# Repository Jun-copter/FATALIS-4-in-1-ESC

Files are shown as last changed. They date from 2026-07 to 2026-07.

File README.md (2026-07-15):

# FATALIS — 4-in-1 ESC

> **⚠ Work in Progress** — PCB layout and schematic are still under active development. Not yet sent for fabrication.

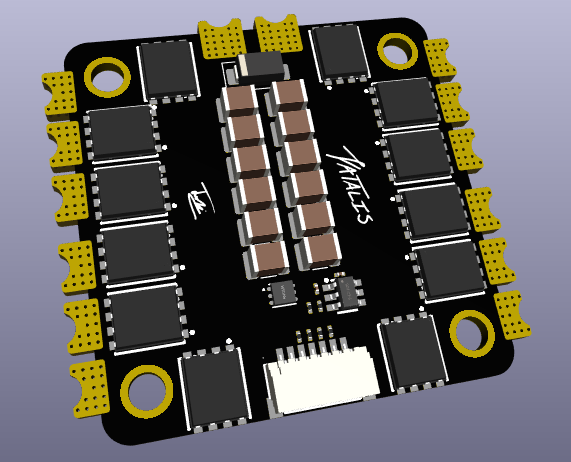
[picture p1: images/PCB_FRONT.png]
PCB 3D render (front)


<em>3D render — in progress, not final</em>

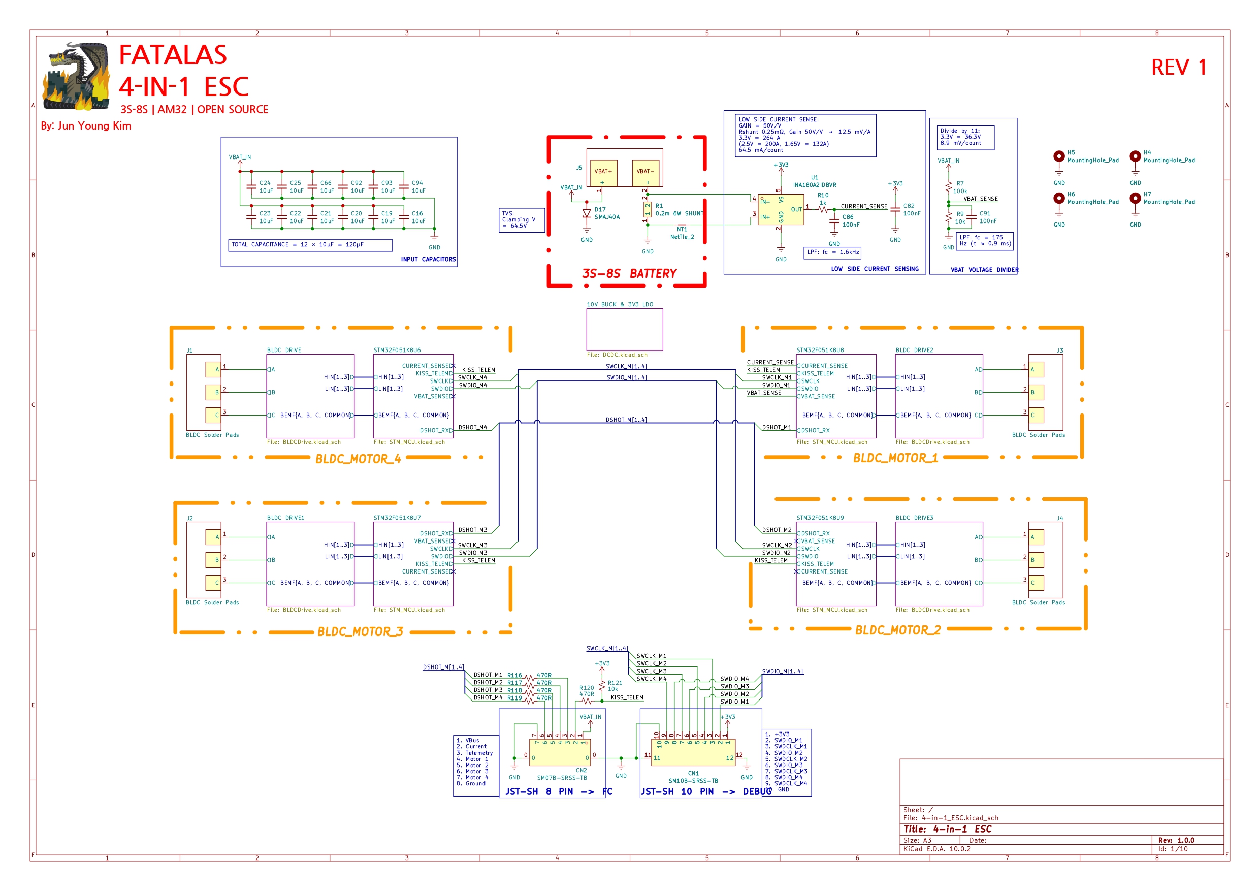
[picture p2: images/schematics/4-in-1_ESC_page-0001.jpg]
Top-level schematic


<em>Top-level schematic</em>

A compact 4-in-1 brushless ESC designed for high-performance FPV racing and freestyle drones. Four independent motor drives on a single 40×40mm 6-layer PCB, each rated 45A continuous / 90A burst per motor, running AM32 open-source firmware on an STM32G071. Sponsored by PCBWay.

---

## Specifications

| Parameter | Value |
|---|---|
| Input voltage | 3–8S LiPo (11–33.6V) |
| Continuous current | 45A per motor (phase current, with prop-wash airflow) |
| Burst current | 90A per motor (phase current, <10s) |
| Max input current | ~160A total board (4 motors at full throttle) |
| PCB size | 40mm × 40mm |
| PCB layers | 6 |
| MCU | STM32G071GBU6 × 4 (one per motor) |
| Firmware | AM32 (open-source) |
| MOSFETs | Infineon BSC070N10NS3G (100V, 7mΩ) |
| Gate driver | JSM6288Q half-bridge |
| Power regulator | TI LMR51610 buck (→10V) + TI TLV76733 LDO (→3.3V) |
| Protocols | DShot150/300/600, Oneshot125/42, Multishot, PWM |
| Telemetry | KISS / AM32 ESC telemetry (RPM, current, voltage, temperature) |
| Sensing | Per-motor current, battery voltage, temperature |

---

## Board Design

### Power Architecture

The input rail accepts 3–8S LiPo (up to 33.6V) and feeds directly into the MOSFET phase bridges. A TI **LMR51610** wide-VIN synchronous buck converter steps the battery voltage down to 10V at 400kHz, sized with a 56µH inductor and 22µF output filter for low ripple. A TI **TLV76733** LDO then regulates the 10V rail to a clean 3.3V supply for the MCUs and logic. Input bulk capacitors are 100V-rated ceramics with capacitance derating analysis applied (~50% effective capacitance at DC bias), ensuring adequate hold-up under the fast transients of motor switching.

### MOSFET Phase Bridges

Each of the four motor drives uses six **Infineon BSC070N10NS3G** N-channel MOSFETs (100V, 7mΩ) arranged in a standard 3-phase half-bridge topology. The 100V rating provides margin above the maximum 33.6V battery voltage, accounting for inductive flyback spikes during hard switching. Gate resistors and RC snubbers suppress ringing on the switch node without significantly degrading switching speed. The continuous current rating is thermally derived: at 45A phase current, conduction losses across the two active MOSFETs (I²×2×R_DS(on)_hot) stay within the thermal budget of the 6-layer copper pours under prop-wash cooling, keeping junction temperature below 125°C with a 50°C ambient.

### Gate Drive

**JSM6288Q** bootstrap half-bridge gate drivers provide high-current drive capability for fast MOSFET switching, with integrated bootstrap diodes charging the high-side gate supply on each PWM cycle. Bootstrap capacitors are sized to maintain sufficient gate drive voltage across the full duty-cycle range at maximum switching frequency.

### MCU & Firmware

Each motor channel has a dedicated **STM32G071GBU6** (Cortex-M0+, 64MHz) running **AM32** open-source ESC firmware. AM32's timer-based protocol auto-detection supports DShot150/300/600, Oneshot125/42, Multishot, and standard PWM without manual configuration. The STM32G071's advanced timers handle 3-phase complementary PWM generation with configurable dead-time insertion.

### Sensing & Telemetry

**Input current sensing** uses two **ASR-M-3-0.5F** (0.5mΩ, 6W, 2512) shunt resistors in parallel on the low side, giving an effective 0.25mΩ shunt rated 12W total. At maximum board input current (180A across all four motors at full throttle), each shunt carries 90A and dissipates 4.05W — within the 6W per-unit rating with comfortable margin. An **INA180A2IDBVR** current sense amplifier (gain = 50V/V) reads the differential voltage across the shunt; at 180A the output is 2.25V, well within the 3.3V ADC rail. Low-side placement keeps the common-mode voltage near 0V, so the INA180A2's 26V common-mode limit is not a concern across the full 3–8S input range.

**Per-motor current sensing** uses a dedicated low-side shunt on each phase leg, read by the STM32G071's internal ADC for real-time per-motor current feedback to AM32 firmware.

Battery voltage is monitored through a resistor divider, and an NTC thermistor on each motor channel provides board temperature. All sensor data is transmitted back to the flight controller over bidirectional DShot as KISS/AM32 telemetry frames, providing real-time RPM, current, voltage, and temperature at full loop rates.

### Thermal Design

Power dissipation analysis was performed on both the switching MOSFETs and the LMR51610 buck converter using junction-to-ambient and ψ_JB thermal metrics. At 45A continuous, conduction losses per motor (P = I²×2×R_DS(on)_hot ≈ 60W split across 6 MOSFETs) are managed by direct solder of exposed pads to the PCB and inner-layer copper pours acting as a thermal spreader. The 6-layer stackup provides additional thermal mass compared to a 4-layer design.

---

## Connectors

### 8-Pin JST — Flight Controller

| Pin | Signal |
|-----|---|
| 1 | VBus |
| 2 | Current |
| 3 | Telemetry |
| 4 | Motor 1 |
| 5 | Motor 2 |
| 6 | Motor 3 |
| 7 | Motor 4 |
| 8 | Ground |

### 10-Pin JST — Debug / SWD

| Pin | Signal |
|-----|---|
| 1 | +3V3 |
| 2 | SWDIO M1 |
| 3 | SWDCLK M1 |
| 4 | SWDIO M2 |
| 5 | SWDCLK M2 |
| 6 | SWDIO M3 |
| 7 | SWDCLK M3 |
| 8 | SWDIO M4 |
| 9 | SWDCLK M4 |
| 10 | GND |

---

## Schematics

### Top-Level Overview
<table>
  <tr>
    <td>PCB 3D render (front)</td>
    <td>Top-level schematic</td>
  </tr>
</table>

### BLDC Drive — Motor 1
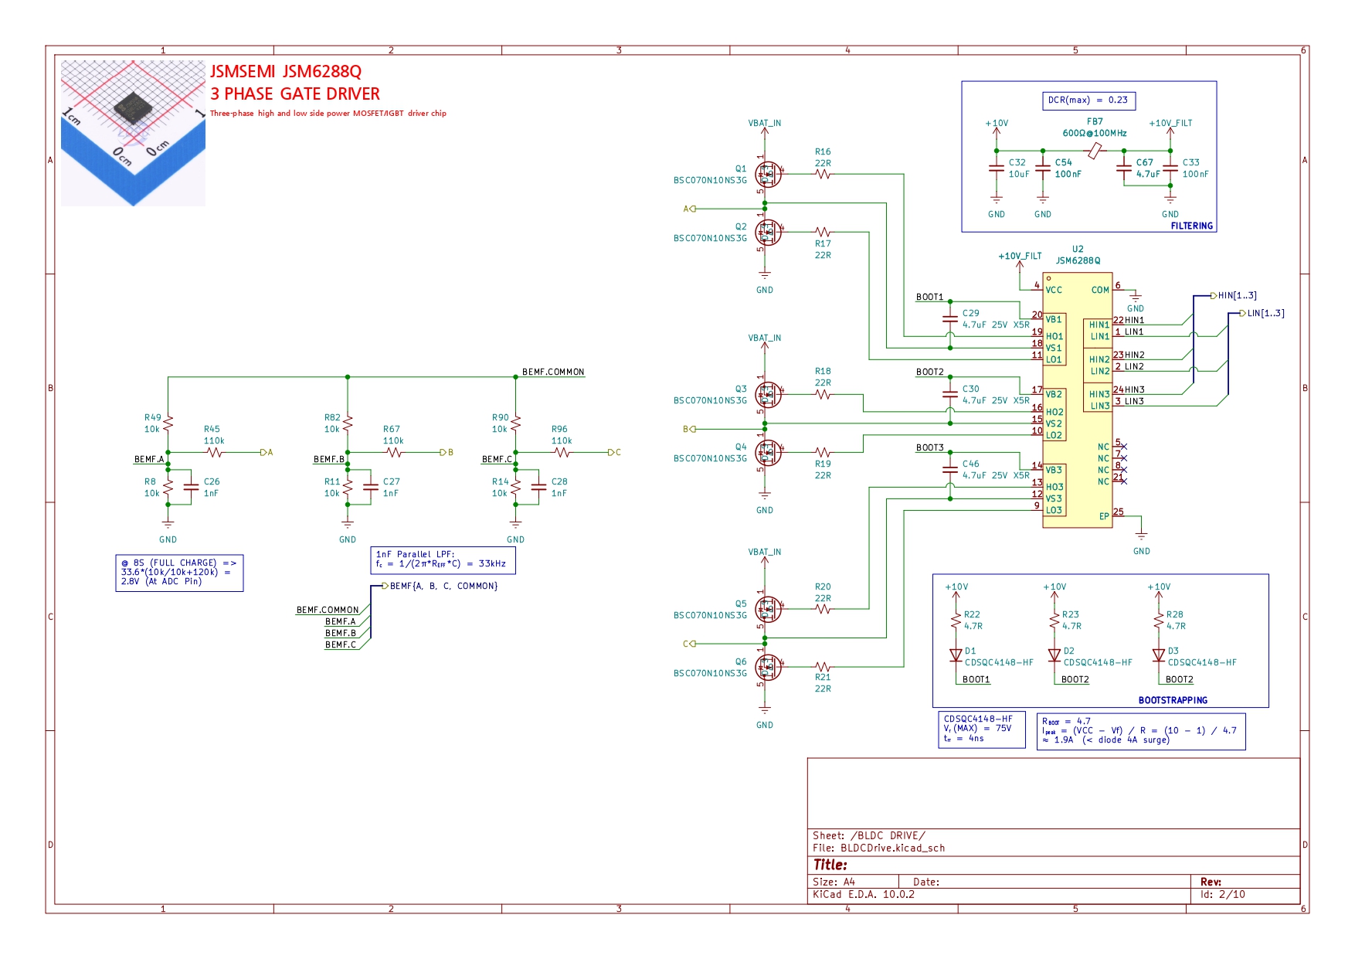
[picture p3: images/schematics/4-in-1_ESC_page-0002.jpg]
BLDC Drive Motor 1


### MCU — Motor 1 (STM32G071GBU6)
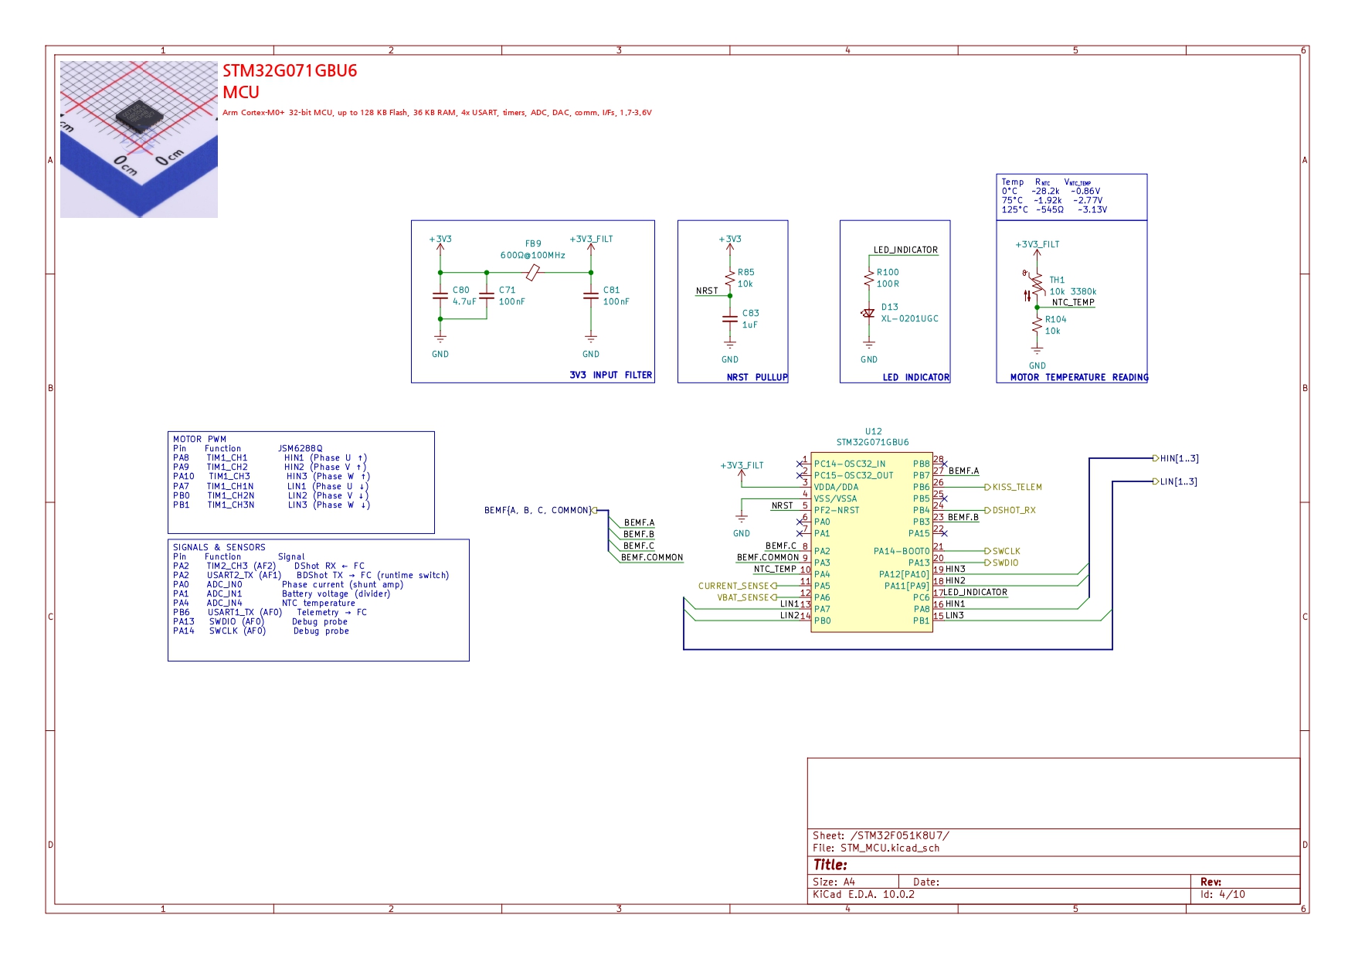
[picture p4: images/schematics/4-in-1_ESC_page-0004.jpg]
MCU Motor 1


### BLDC Drive — Motor 2
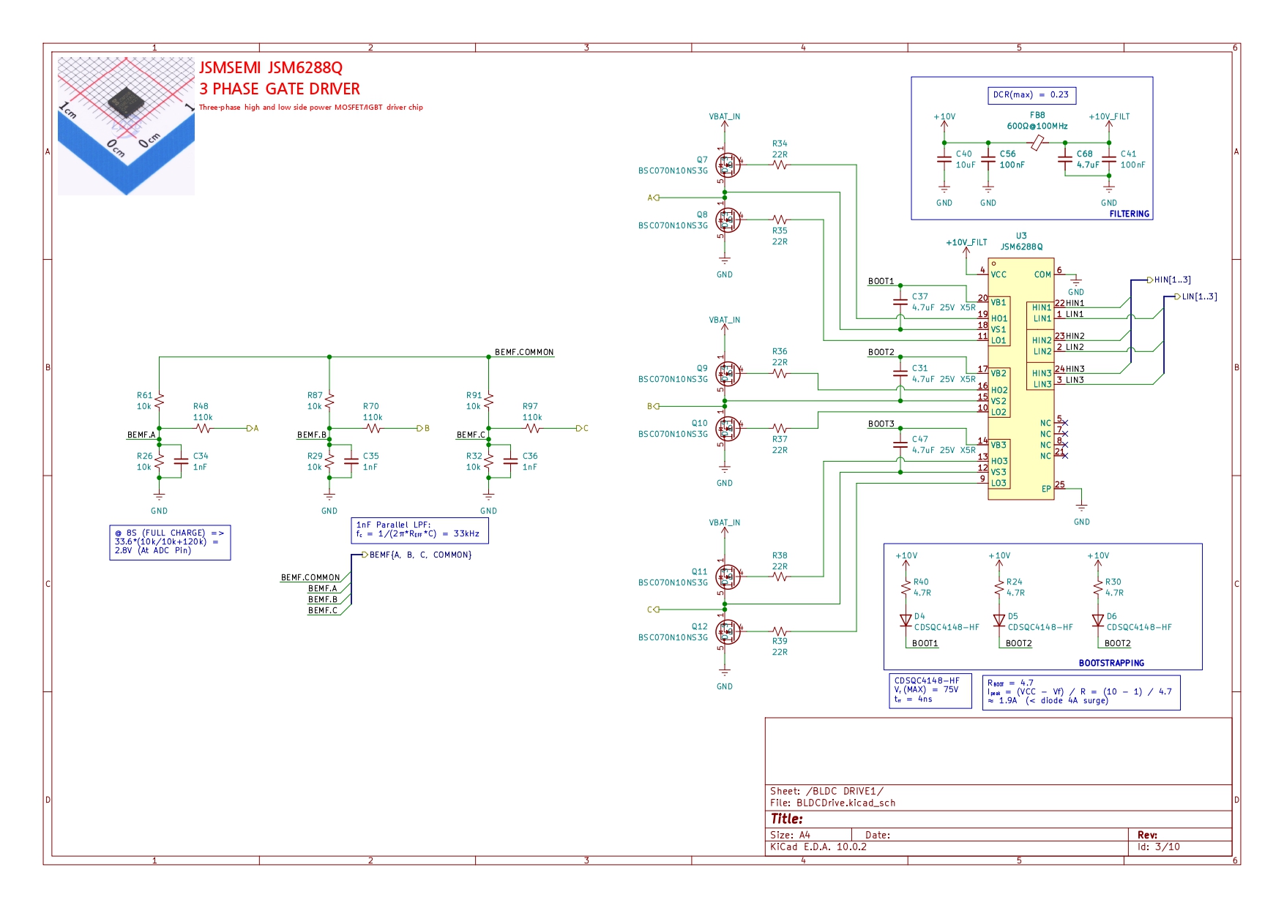
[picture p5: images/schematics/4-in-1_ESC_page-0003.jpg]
BLDC Drive Motor 2


### MCU — Motor 2 (STM32G071GBU6)
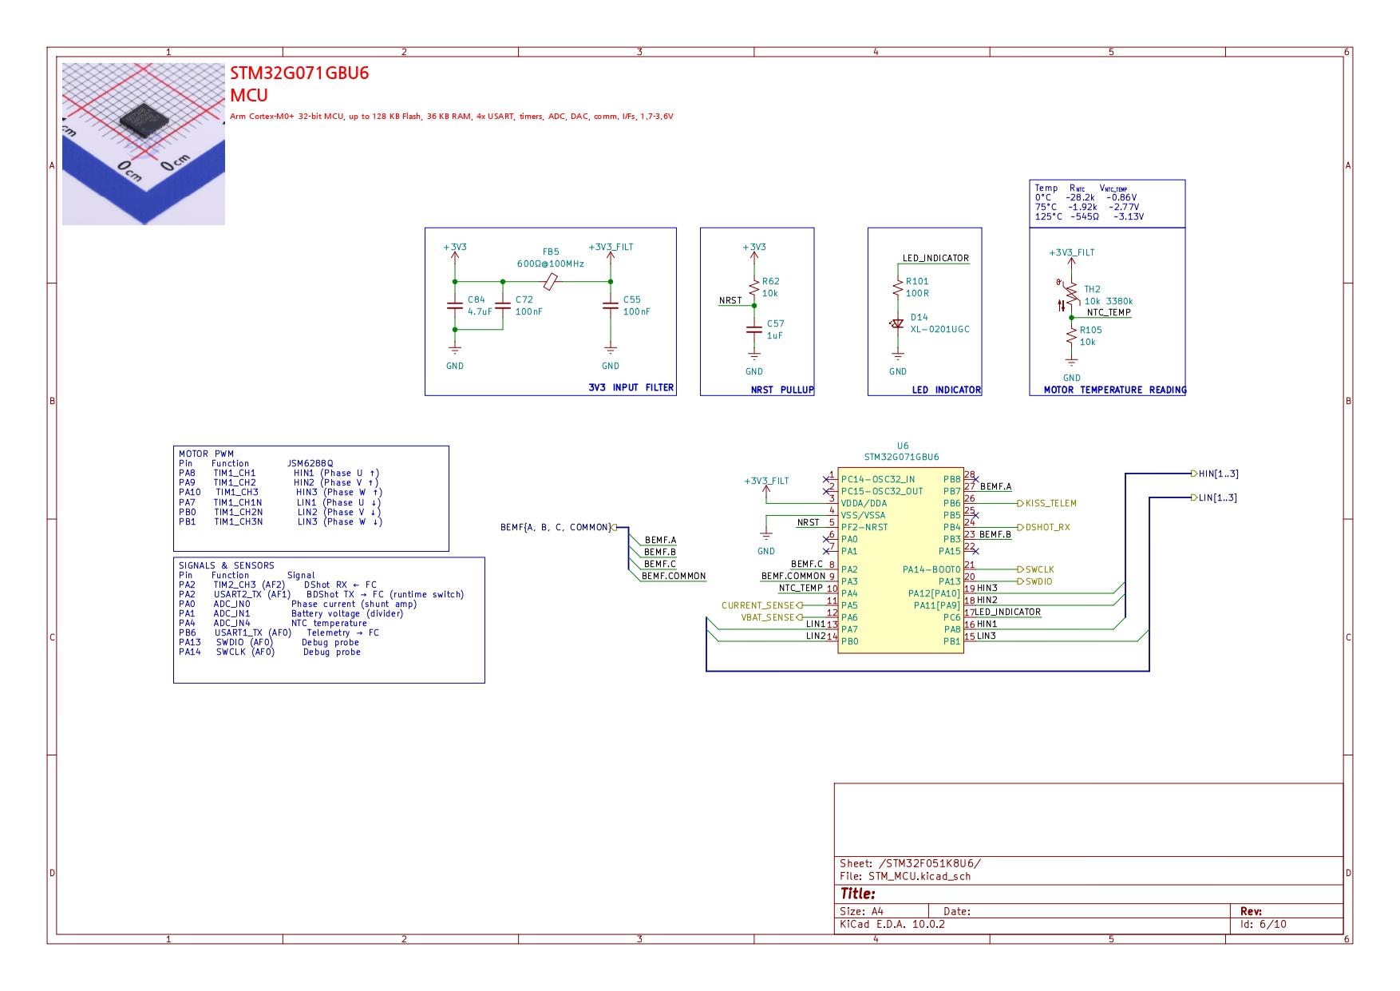
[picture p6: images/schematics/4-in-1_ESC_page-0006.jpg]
MCU Motor 2


### BLDC Drive — Motor 3
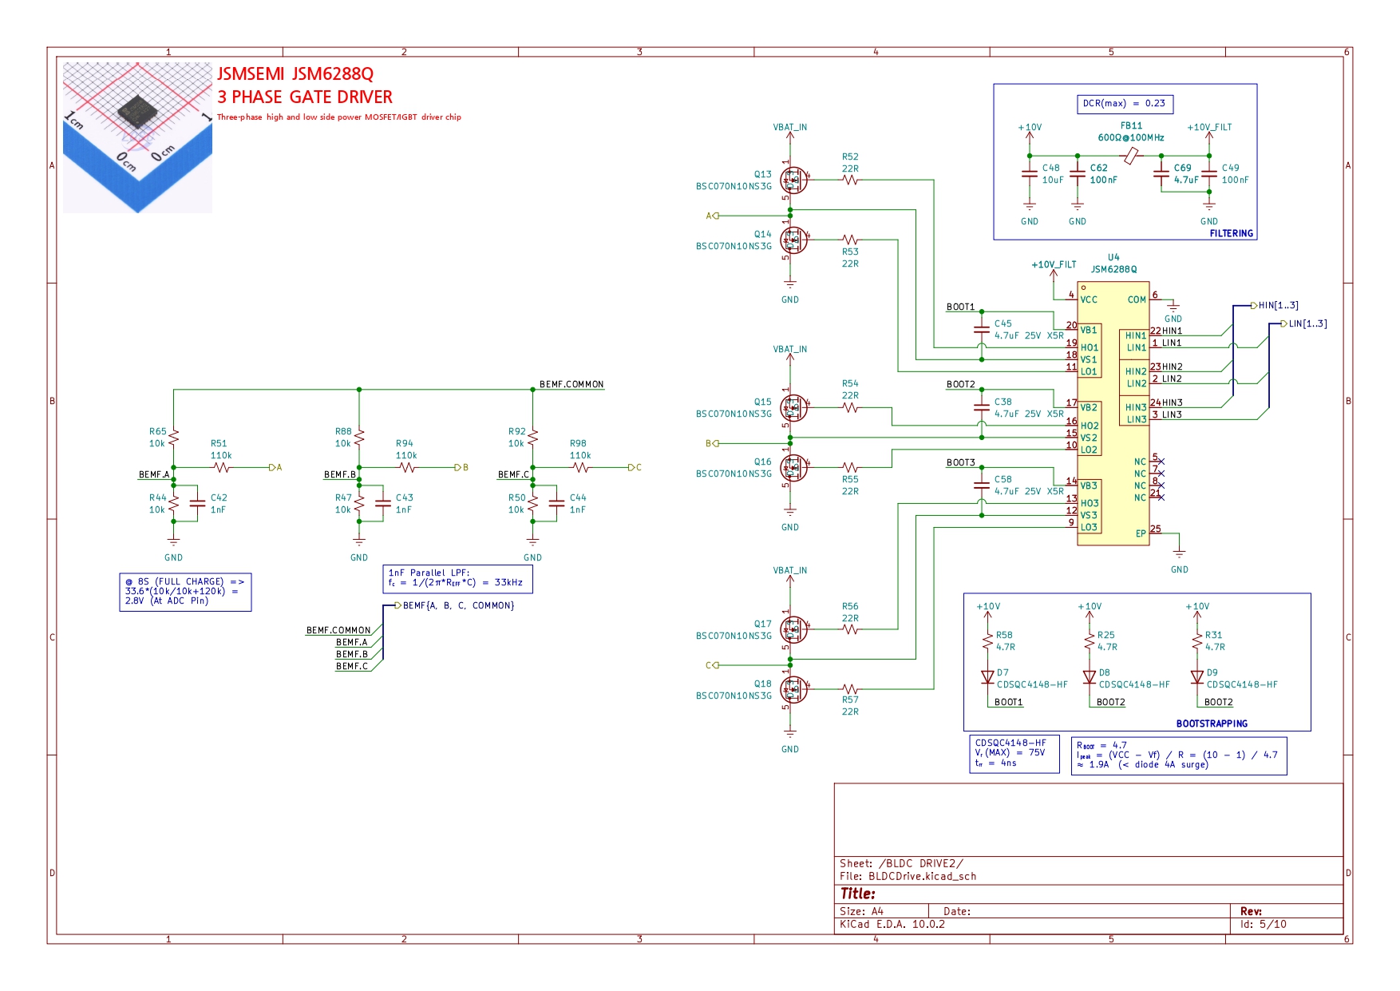
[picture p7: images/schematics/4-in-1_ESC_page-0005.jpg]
BLDC Drive Motor 3


### MCU — Motor 3 (STM32G071GBU6)
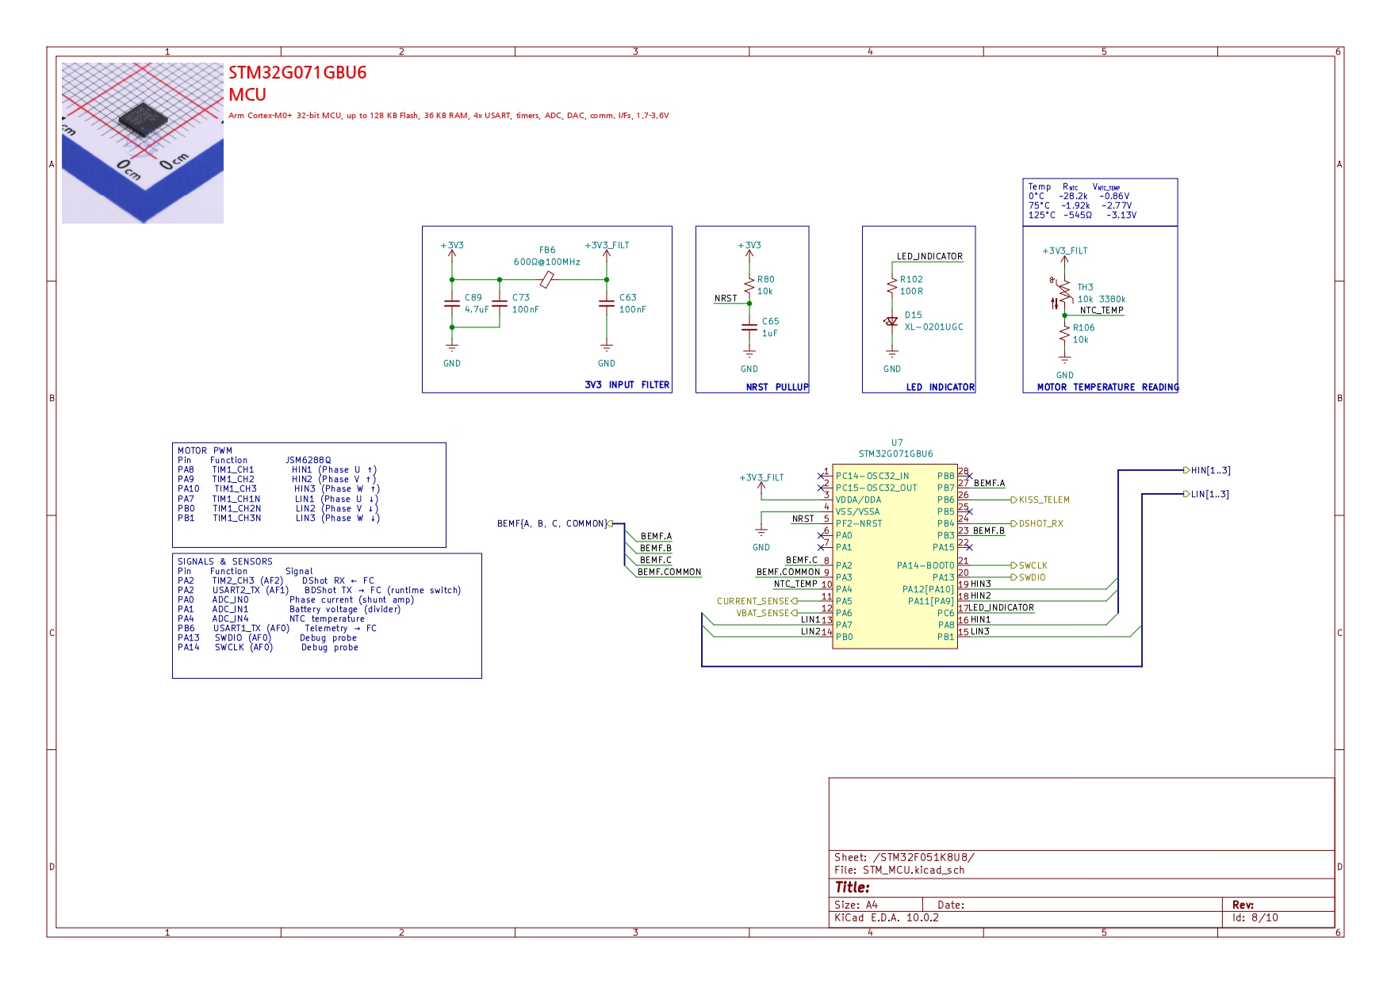
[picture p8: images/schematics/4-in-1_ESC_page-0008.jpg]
MCU Motor 3


### BLDC Drive — Motor 4
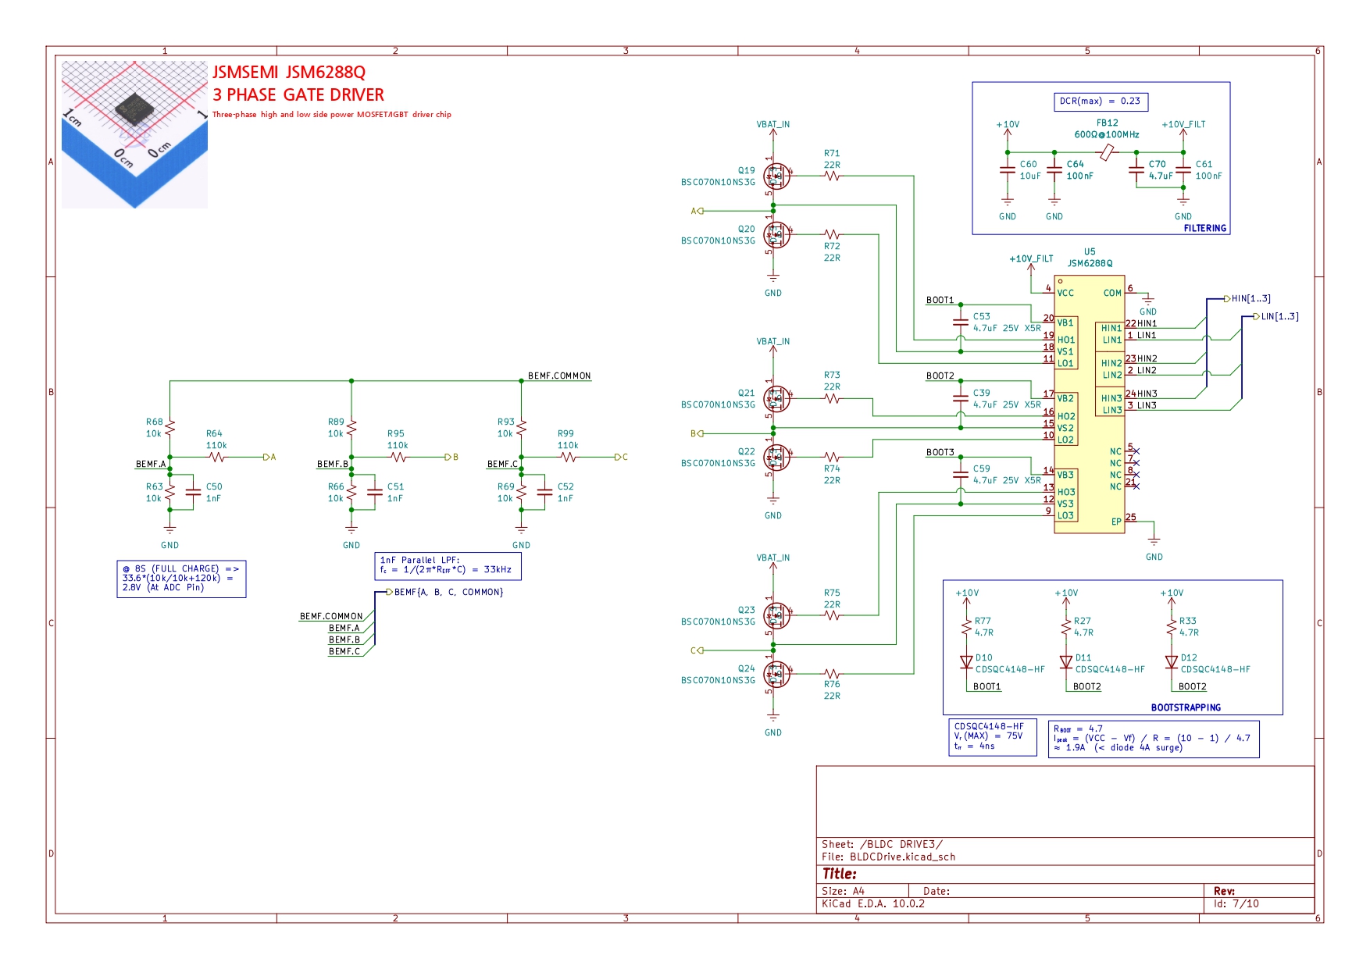
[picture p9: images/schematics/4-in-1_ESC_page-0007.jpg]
BLDC Drive Motor 4


### MCU — Motor 4 (STM32G071GBU6)
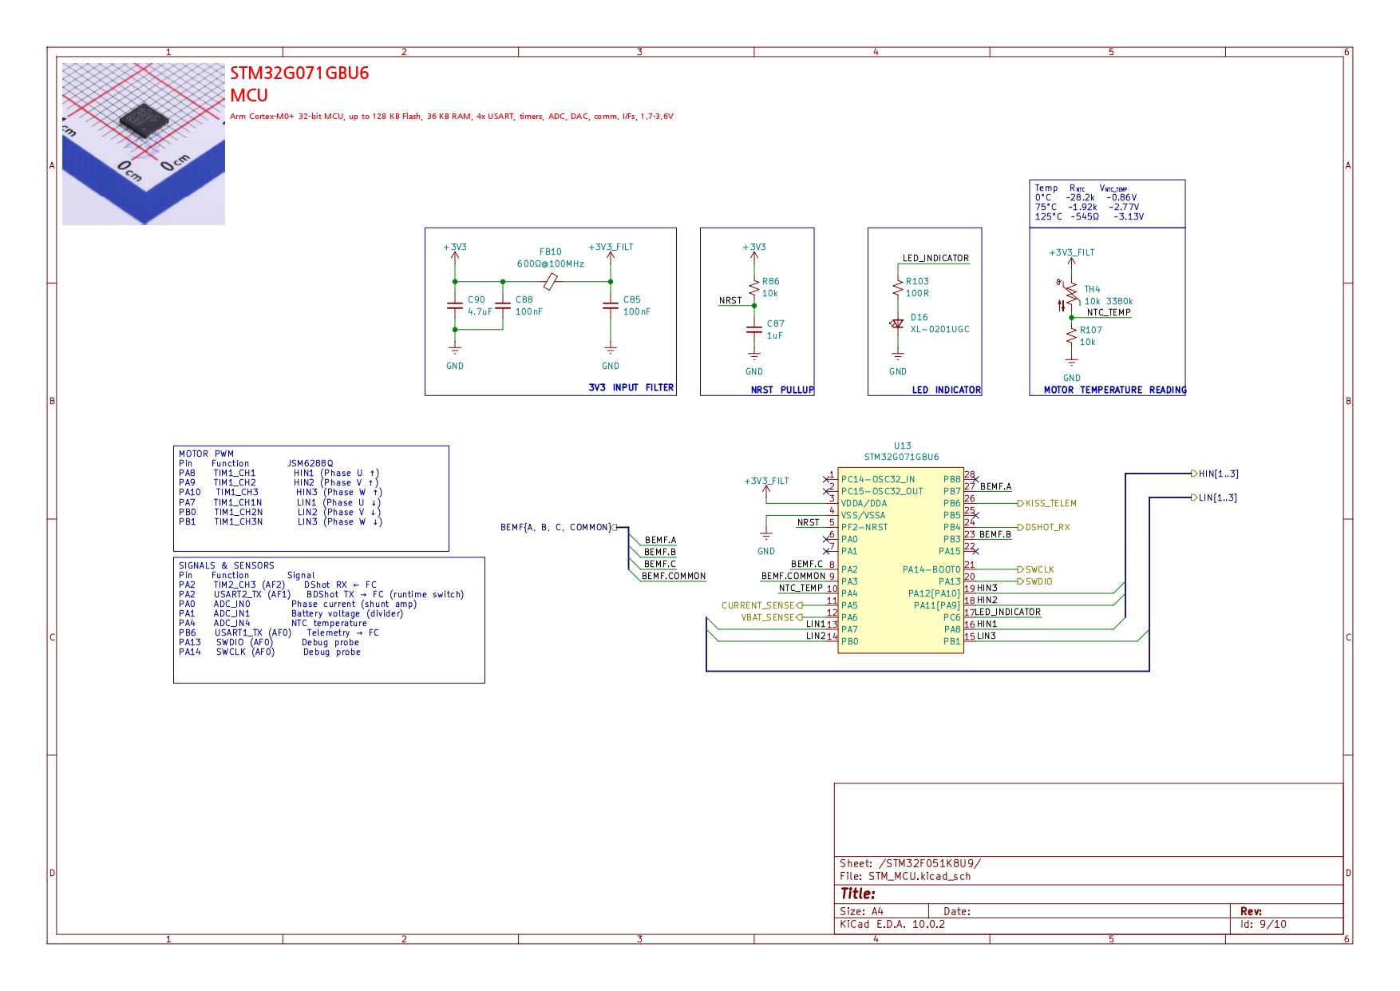
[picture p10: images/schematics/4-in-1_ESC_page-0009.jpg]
MCU Motor 4


### Power Supply — 10V Buck & 3.3V LDO
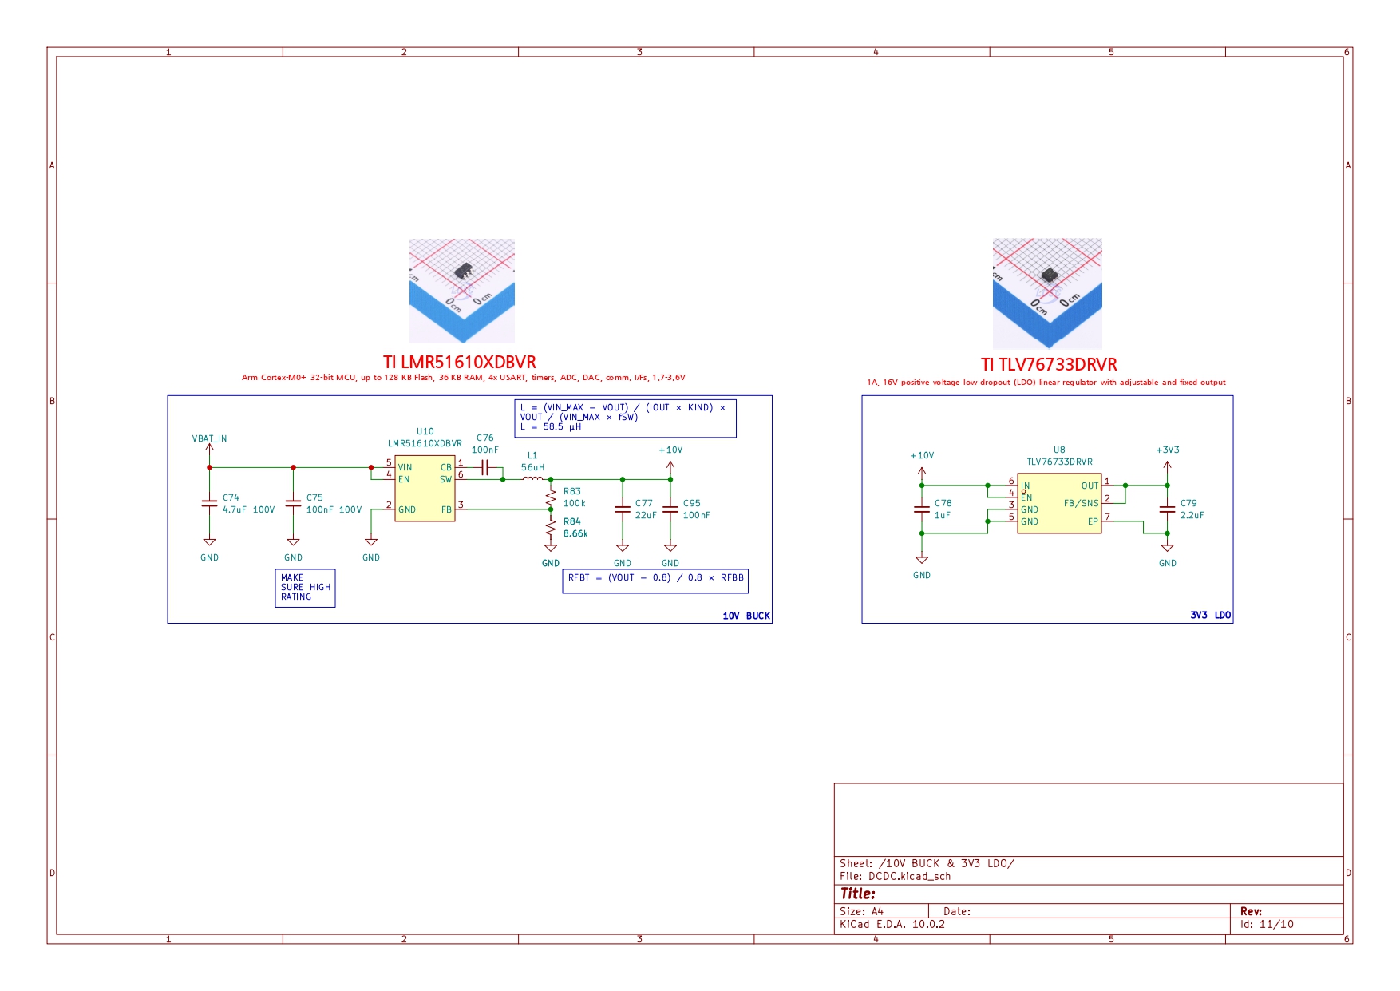
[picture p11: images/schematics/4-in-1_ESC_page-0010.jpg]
Power Supply


---

## Repository Layout

| File / Folder | Contents |
|---|---|
| `4-in-1_ESC.kicad_pro` | KiCad project file |
| `4-in-1_ESC.kicad_sch` | Top-level schematic |
| `BLDCDrive.kicad_sch` | BLDC motor drive sub-sheet |
| `DCDC.kicad_sch` | Power supply sub-sheet |
| `STM_MCU.kicad_sch` | STM32G071 MCU sub-sheet |
| `I_V_SENSE.kicad_sch` | Current / voltage sensing sub-sheet |
| `4-in-1_ESC.kicad_pcb` | PCB layout |
| `libs/` | Symbols, footprints, and 3D models |
| `images/schematics/` | Schematic export images |

---

*Sponsored by [PCBWay](https://www.pcbway.com)*

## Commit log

2026-06-04 Schematic Updates
    [4-in-1_ESC.kicad_sch, 9V_BUCK.kicad_sch, BLDCDrive.kicad_sch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]
2026-06-28 Schematic First Pass
    [4-in-1_ESC.kicad_pcb, 4-in-1_ESC.kicad_sch, BLDCDrive.kicad_sch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]
2026-07-14 Move KiCad project files to repo root
    All files previously nested under 4-in-1_ESC/ are now at the top level
    so they are visible directly on GitHub without navigating into a subfolder.
    Also updated CLAUDE.md to reflect the new paths.
    [10V_BUCK.kicad_sch, 4-in-1_ESC.kicad_pcb, 4-in-1_ESC.kicad_sch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]
2026-07-14 Expand README and remove script from tracking
    - Add detailed board description: power tree, MOSFETs, gate drive,
    MCU/AM32 firmware, sensing/telemetry, and thermal design sections
    - Drop add-lcsc-part.ps1 from git (added to .gitignore); file kept locally
2026-07-14 Clarify current rating as phase current in README
2026-07-15 Update current ratings to thermally honest values (45A/90A)
2026-07-15 Add schematic images and update README layout
    - Add images/schematics/ with all 10 schematic pages as JPGs
    - Hero image (top-level overview) at top of README
    - Full schematics section grouped by subsystem: BLDC drive,
    MCU, and power supply per motor channel
2026-07-15 Update README: document input current sensing design
    Two ASR-M-3-0.5F (0.5mΩ, 6W) in parallel → 0.25mΩ / 12W,
    INA180A2 (gain 50), 2.25V output at 180A, low-side placement.
2026-07-15 Add PCB 3D render and pair with schematic in hero and schematics section
2026-07-15 Add work-in-progress notice and PCB render caption
2026-07-15 Increase PCB front render image width to 500px
2026-07-15 Make PCB render full-width, stack images vertically
2026-07-15 Add connector pinout tables (FC 8-pin and debug 10-pin)
